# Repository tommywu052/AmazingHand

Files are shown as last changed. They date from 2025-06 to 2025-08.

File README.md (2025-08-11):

Project is licensed under [Apache 2.0](https://www.apache.org/licenses/LICENSE-2.0)

Mechanical design is licensed under a :
[Creative Commons Attribution 4.0 International License][cc-by].
[][cc-by]
[][cc-by]

[cc-by]: http://creativecommons.org/licenses/by/4.0/
[cc-by-image]: https://licensebuttons.net/l/by/4.0/88x31.png
[cc-by-shield]: https://img.shields.io/badge/License-CC%20BY-lightgrey.svg

# Amazing Hand project

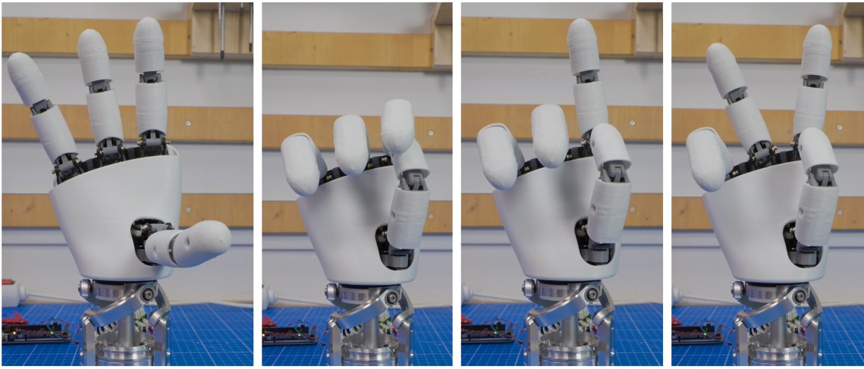
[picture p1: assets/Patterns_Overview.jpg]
Patterns


Robotic hands are often very expensive and not so expressive. More dexterous often needs cables and deported actuators in forearm i.e..

Aim of this project is to be able to explore humanoid hand possibilities on a real robot (and Reachy2 is the perfect candidate for that !) with moderate cost.
=> Wrist interface is designed for Reachy2's wrist (Orbita 3D), but it can be easily adapted to other robot's wrist...

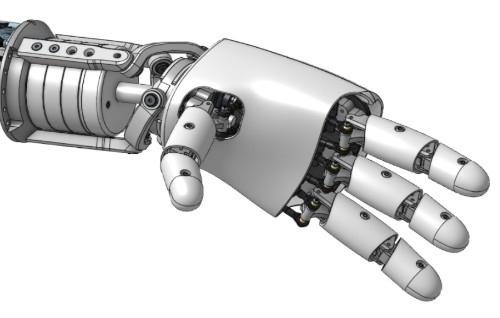
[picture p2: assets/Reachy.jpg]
Reachy


Amazing Hand is :
- 8 dofs humanoid hand with 4 fingers
- 2 phalanxes per finger articulated together
- flexible shells allmost everywhere
- All actuators inside the hand, without any cables
- 3D printable
- 400g weight
- low-cost (<200€)
- open-source

[AmazingHand_Overview](/docs/AmazingHand_Overview.pdf)

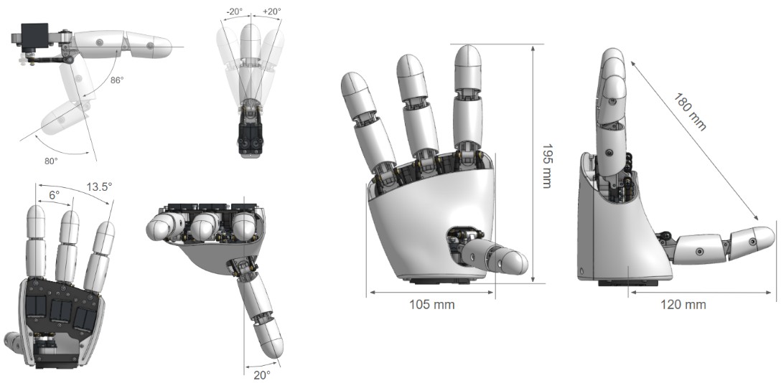
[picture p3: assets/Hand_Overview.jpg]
Hand Overview

Each finger is driven by parallel mechanism. 
That means 2x small Feetech SCS0009 servos are used to move each finger in flexion / extension & Abduction / Adduction

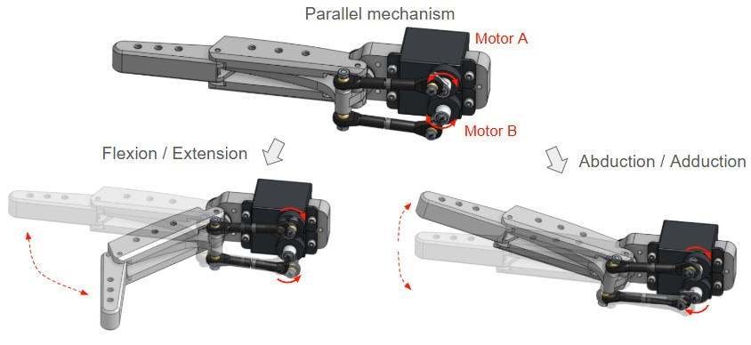
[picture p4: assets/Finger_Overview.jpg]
Finger Overview


2 ways of control are available :
- Use a Serial bus driver (waveshare i.e.) + Python script
- Use an Arduino + feetech TTL Linker

Detailed explaination are available for both ways and Basic demo software is available also.
Up to you !

## Table of contents

- [Python-based Hand Tracking System](#python-based-hand-tracking-system)
    - [Features](#features)
    - [Files](#files)
    - [Quick Start](#quick-start)
    - [Command Line Options](#command-line-options)
    - [Installation](#installation)
        - [CPU Version (Default)](#cpu-version-default)
        - [GPU Version (Enhanced Performance)](#gpu-version-enhanced-performance)
    - [Simulation Mode](#simulation-mode)
    - [Testing and Troubleshooting](#testing-and-troubleshooting)
    - [Control Modes](#control-modes)
    - [Configuration](#configuration)
    - [Hardware Requirements](#hardware-requirements)
    - [GPU Performance Optimization](#gpu-performance-optimization)
- [Build Resources](#build-resources)
    - [BOM (Bill Of Materials)](#bom-bill-of-materials)
    - [CAD Files and Onshape document](#CAD-files-and-onshape-document)
    - [Assembly Guide](#assembly-guide)
    - [Run_basic_Demo](#Run-basic-Demo)
- [Disclaimer](#disclaimer)
- [AmazingHand_tracking Demo](#AmazingHand_tracking_Demo) 
- [Project Updates & Community](#project-updates--community)
    - [Updates history](#updates-history)
    - [Project posts](#project-posts)
    - [To Do List](#to-do-list)
    - [FAQ](#faq)
    - [Contact](#contact)
    - [Thank you](#thank-you)

# Python-based Hand Tracking System

A new Python-based hand tracking system has been developed that provides real-time control of the Amazing Hand using MediaPipe hand tracking and inverse kinematics.

## Features

- **Real-time Hand Tracking**: Uses MediaPipe to detect hand landmarks from video stream
- **Inverse Kinematics**: Implements curl-based IK for natural finger movement control
- **Direct Motor Control**: Communicates directly with Feetech SCS0009 servos via serial connection
- **Natural Movement**: Robot fingers mimic physical hand movements including bending and positioning
- **Configurable Parameters**: Adjustable sensitivity, movement ranges, and motor positions

## Files

- **`amazing_hand_tracker_simple.py`**: Main Python script for hand tracking and robot control
- **`scsservo_sdk/`**: Custom SDK for Feetech SCS0009 servo communication
- **`r_hand.json`**: Robot hand configuration file with motor mappings
- **`requirement_simple.txt`**: Python dependencies for the tracking system (CPU version)
- **`requirements_gpu.txt`**: GPU-accelerated dependencies for enhanced performance

## Quick Start

1. Install dependencies:
   ```bash
   pip install -r requirement_simple.txt
   ```

2. Connect the Amazing Hand to your computer via USB (COM port on Windows)

3. Run the tracking system:
   ```bash
   python amazing_hand_tracker_simple.py --port COM3
   ```

4. Show your hand to the camera - the robot fingers will follow your movements

## Command Line Options

The script supports various command line arguments for different modes and configurations:

```bash
# Basic hand tracking with robot control
python amazing_hand_tracker_simple.py --port COM3

# Simulation mode (no physical robot connection)
python amazing_hand_tracker_simple.py --simulation

# Test individual motors
python amazing_hand_tracker_simple.py --test-motors --port COM3

# Enable debug output
python amazing_hand_tracker_simple.py --port COM3 --debug

# Use advanced IK instead of curl-based IK
python amazing_hand_tracker_simple.py --port COM3 --advanced-ik

# Specify different COM port
python amazing_hand_tracker_simple.py --port COM4

# Force GPU acceleration (if available)
python amazing_hand_tracker_simple.py --port COM3 --gpu

# Help and available options
python amazing_hand_tracker_simple.py --help
```

## Installation

### Prerequisites
- Python 3.7 or higher
- Webcam for hand tracking
- USB-to-Serial converter (for physical robot connection)

### Dependencies Installation

#### CPU Version (Default)
Install all required packages:
```bash
pip install -r requirement_simple.txt
```

Or install manually:
```bash
pip install opencv-python
pip install mediapipe
pip install numpy
pip install pyserial
```

#### GPU Version (Enhanced Performance)
For better performance with GPU acceleration, install GPU-enabled versions:

**⚠️ Important**: GPU acceleration support varies by Python version:

**Python 3.11 or earlier (Full GPU acceleration):**
```bash
# CUDA-enabled OpenCV (for NVIDIA GPUs)
pip install opencv-python-cuda

# GPU-accelerated MediaPipe
pip install mediapipe-gpu

# GPU-accelerated NumPy (optional, for large calculations)
pip install cupy-cuda11x  # Replace with your CUDA version

# Other dependencies remain the same
pip install pyserial
```

**Python 3.12 (Limited GPU acceleration - Current):**
```bash
# Standard packages (GPU acceleration limited)
pip install opencv-contrib-python
pip install mediapipe
pip install pyserial

# PyTorch with CUDA (this works on Python 3.12)
pip install torch torchvision torchaudio --index-url https://download.pytorch.org/whl/cu121
```

**Note**: GPU versions require:
- NVIDIA GPU with CUDA support
- CUDA Toolkit installed
- Compatible GPU drivers
- Windows: Visual Studio Build Tools
- Linux: GCC compiler

**Performance Benefits**:
- Faster hand tracking processing
- Reduced latency for real-time control
- Better performance with high-resolution cameras
- Smoother robot hand response

### Hardware Setup
1. Connect the Amazing Hand to your computer via USB
2. Ensure external 5V power supply is connected to the servos
3. Note the COM port (e.g., COM3 on Windows, /dev/ttyUSB0 on Linux)

## Simulation Mode

For testing without physical hardware, use simulation mode:
```bash
python amazing_hand_tracker_simple.py --simulation
```

In simulation mode:
- MediaPipe hand tracking works normally
- Motor commands are simulated (no physical movement)
- Useful for testing hand detection and IK calculations
- No COM port connection required

## Testing and Troubleshooting

### Test Motor Connections
```bash
python amazing_hand_tracker_simple.py --test-motors --port COM3
```

This will:
- Test communication with each servo
- Move each finger through its range of motion
- Verify motor IDs and connections
- Display servo feedback and status

### Debug Mode
```bash
python amazing_hand_tracker_simple.py --port COM3 --debug
```

Enables:
- Detailed console output
- Motor position logging
- IK calculation details
- MediaPipe landmark coordinates

## Control Modes

- **Curl-based IK**: Maps finger curl (bending) to servo positions for natural movement
- **Advanced IK**: Alternative inverse kinematics approach (experimental)
- **Test Mode**: Test individual motors and verify connections

## Configuration

The system can be configured through parameters in the Python script:
- `CURL_GAIN_PER`: Sensitivity of finger bending
- `OPEN_POS_PER`/`CLOSE_POS_PER`: Position limits for each finger
- `CENTER_OFFSET`: Compensation for finger alignment
- `MOVEMENT_SMOOTHING`: Smoothing factor for movement response

## Hardware Requirements

- Amazing Hand with Feetech SCS0009 servos
- USB-to-Serial converter (or direct USB connection)
- Webcam for hand tracking
- External 5V power supply for servos

## GPU Performance Optimization

### When to Use GPU Version
- **High-resolution cameras** (1080p or higher)
- **Multiple hand tracking** scenarios
- **Low-latency requirements** for real-time control
- **Processing-intensive applications** with complex IK calculations

### Performance Comparison
| Feature | CPU Version | GPU Version | Improvement |
|---|---|---|---|
| Hand tracking speed | ~30 FPS | ~60+ FPS | 2x faster |
| Latency | ~33ms | ~16ms | 2x lower |
| Camera resolution | Up to 720p | Up to 4K | 4x higher |
| Multi-hand support | Limited | Excellent | Significant |

### GPU Requirements
- **NVIDIA GPU**: GTX 1060 or better (6GB+ VRAM recommended)
- **CUDA Support**: CUDA 11.0 or higher
- **Driver Version**: Latest NVIDIA drivers
- **Memory**: 8GB+ system RAM, 6GB+ VRAM

### ⚠️ Python Version Compatibility
**Important**: GPU acceleration has different levels of support depending on your Python version:

- **Python 3.11 or earlier**: Full GPU acceleration available
  - `opencv-contrib-python-cuda` packages available
  - `mediapipe-gpu` packages available
  - Maximum performance improvement

- **Python 3.12 (Current)**: Limited GPU acceleration
  - PyTorch CUDA support works (detected in your system)
  - MediaPipe falls back to CPU (expected behavior)
  - OpenCV CUDA packages not yet available
  - Still provides some GPU benefits through PyTorch

**Recommendation**: For maximum GPU performance, consider using Python 3.11 until Python 3.12 packages become available.

This system provides a simplified alternative to the original Rust/Dora/Mujoco implementation while maintaining the core functionality of real-time hand tracking and robot control.

# Build Resources
## BOM (Bill Of Materials)
List of all needed components is available here:  
[AmazingHand BOM](https://docs.google.com/spreadsheets/d/1QH2ePseqXjAhkWdS9oBYAcHPrxaxkSRCgM_kOK0m52E/edit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)  
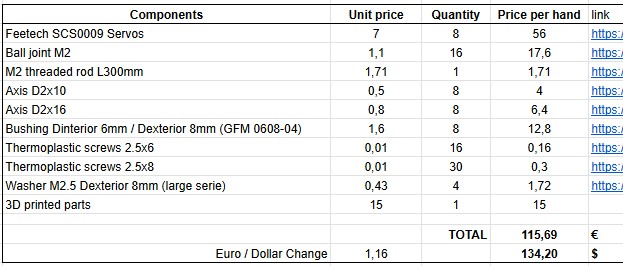
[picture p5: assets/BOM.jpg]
BOM


And remember to add control choice cost (2 options detailed previously)

Detailed for custom 3D printed parts are here : 
[3Dprinted parts](https://docs.google.com/spreadsheets/d/1QH2ePseqXjAhkWdS9oBYAcHPrxaxkSRCgM_kOK0m52E/edit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)

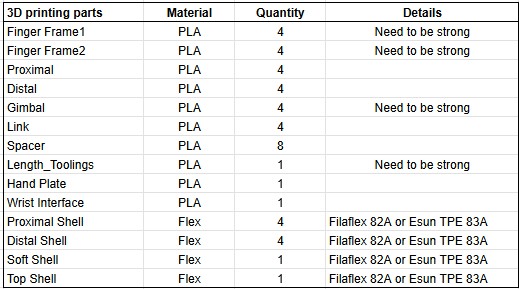
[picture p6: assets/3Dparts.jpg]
3Dparts


Here is guide to explain how to print all the needed custom parts :
[=> 3D Printing Guide](/docs/AmazingHand_3DprintingTips.pdf)
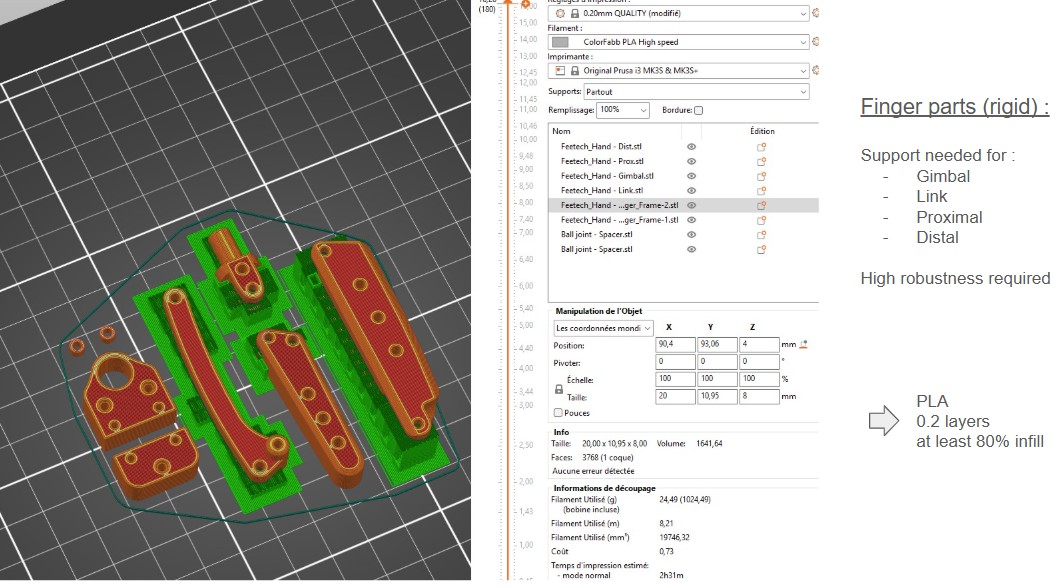
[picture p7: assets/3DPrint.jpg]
3DPrint_example
 

## CAD Files and Onshape document
STL and Steps files can be found [here](https://github.com/pollen-robotics/AmazingHand/tree/main/cad) 

Note that Fingers are the same if you want to build a left hand, but some parts are symetrical. Specific right hand parts are preceded by an "R", and other of the left hand parts by an "L".

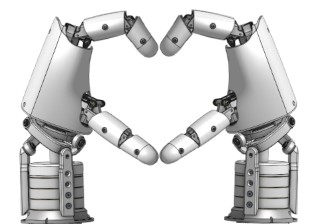
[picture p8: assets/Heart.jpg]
Heart


Everyone can access the Onshape document too:   
[Link Onshape](https://cad.onshape.com/documents/430ff184cf3dd9557aaff2be/w/e3658b7152c139971d22c688/e/bd399bf1860732c6c6a2ee45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)  

Note that predefined position are available in "named position" tooling, with corresponding servos angles

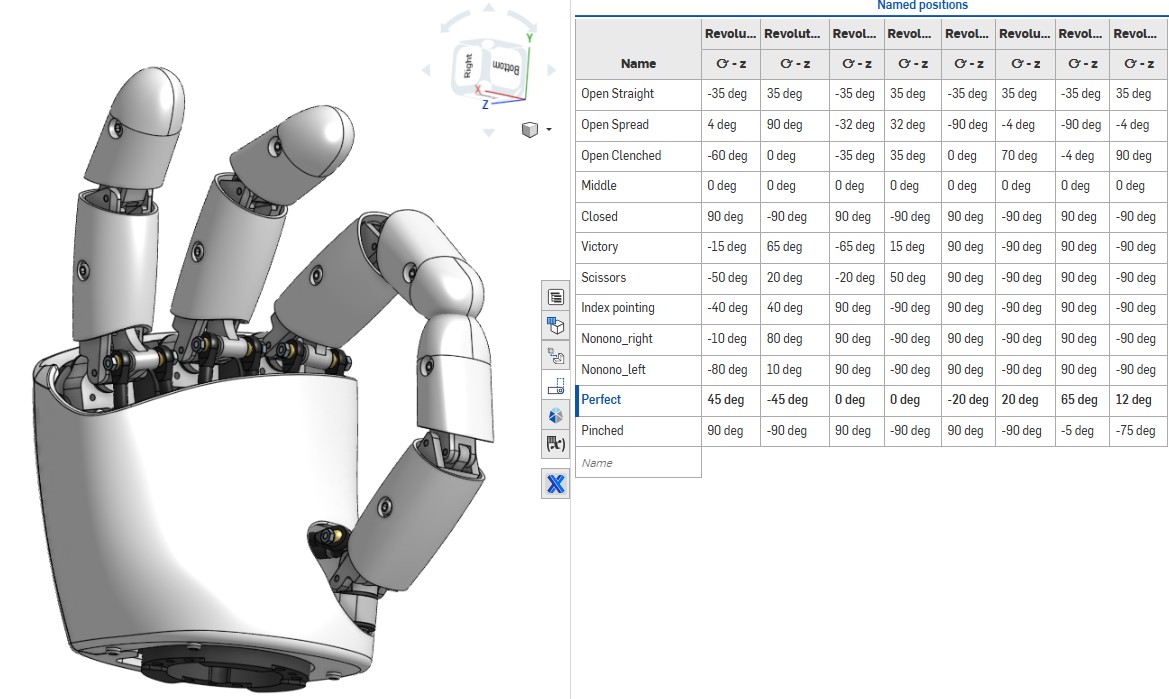
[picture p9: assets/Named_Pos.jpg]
Onshape&Named_Pos
  

## Assembly Guide

Assembly guide for the Amazing Hand in combination with standards components in the BOM is here :  
[=> Assembly Guide](/docs/AmazingHand_Assembly.pdf)  
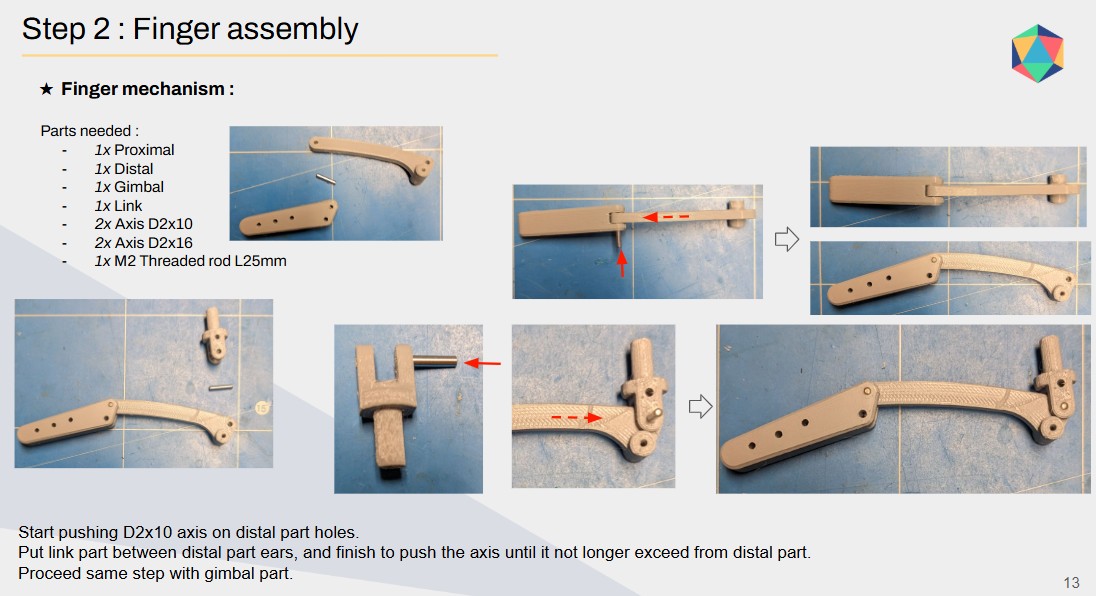
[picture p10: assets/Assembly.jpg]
Assembly_example
  

You will need simple program / script to calibrate each fingers, available here :
- With Python & Waveshare serial bus driver : [here](https://github.com/pollen-robotics/AmazingHand/tree/main/PythonExample)
- With Arduino & TTLinker : [here](https://github.com/pollen-robotics/AmazingHand/tree/main/ArduinoExample)

Note that this assembly guide is for a standalone Right hand.

If you need to build a standalone Left hand, you can keep the sames IDs for servos location, and select if it's a right or left hand in the software.

BUT, if you need to build both right and left hands to plug them on a robot, you will have to attribute differents IDs for right and left hands. You can't have same ID for different servos on the same serial bus...

## Run basic Demo

Basic Demo which is available with both Python & Arduino.

You will need external power supply to be able to power the 8 actuators inside the hand.

If you don't have one already, simple external power supply could be a DC/DC 220V -> 5V / 2A adapter with jack connector.
Check on the Bom List :
[AmazingHand BOM](https://docs.google.com/spreadsheets/d/1QH2ePseqXjAhkWdS9oBYAcHPrxaxkSRCgM_kOK0m52E/edit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) 

- Python script : "AmazingHand_Demo.py" [here](https://github.com/pollen-robotics/AmazingHand/tree/main/ArduinoExample)
  
- Arduino program : "AmazingHand_Demo.ino" [here](https://github.com/pollen-robotics/AmazingHand/tree/main/PythonExample)

https://github.com/user-attachments/assets/485fc1f4-cc57-4e59-90b5-e84518b9fed0

# Disclaimer

I noticed some variations between theorical angles for Flexion / Extension, Abduction / Adduction and angles in real life prototypes. This is probably due to several sources of variation (3D printed parts are not perfect, balljoint rods are manually adjusted one by one, esrvo horn rework, flexibility of plastic parts...).

This design has not yet bene tested for long and complex prehensive tasks. Before to be able to grasp objetcs safely (that means without damaging servos or mehanical parts), kind of smart software need to be build.
SCS0009 servos have smart capaibilities as:
- Torque enable / disable
- Torque feedback
- Current position sensor
- Heat temperature feedback
- ...

# AmazingHand advanced Demo
Tracking demo (https://www.youtube.com/watch?v=U0TfeG3ZUto)

For more advanced usage using inverse/forward kinematics there are several examples in the [Demo](Demo) directory along with some useful tools to test/configure the motors.

# Project Updates & Community
## Updates from community

Amazing Base for the amazing hand : 
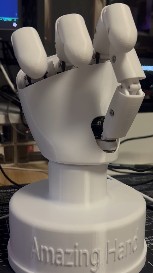
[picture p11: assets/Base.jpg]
Base

STL or Step file can be found [here](https://github.com/pollen-robotics/AmazingHand/tree/main/cad) 

Specific Chinese BOM available here :
[Chinese BOM](https://docs.google.com/spreadsheets/d/1fHZiTky79vyZwICj5UGP2c_RiuLLm89K8HrB3vpb2h4/edit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)

Thanks to Jianliang Shen !

## To Do List
- Design small custom pcb with serial hub and power supply functions, to fit everything in the hand
- Test with prehensive tasks 
      => Add smarter behaviour for closing hand, based on available motors feedbacks
- Study possibility to have 4 different fingers length, or add a 5th finger
- Study possibility to use STS3032 feetedch motors instead of SCS0009
      => Stronger for quite the same volume, but servo horn is different
- Study possibility to add compliancy by replacing rigid links to springs
- Add fingertip sensor to push one step higher smart control

## FAQ
WIP

## Contact

You can reach public discord channel here : 
[Discord AmazingHand](https://discord.com/channels/519098054377340948/1395021147346698300)

Or 
[Contact me or Pollen Robotics](/docs/contact.md)

## Thank you
Huge thanks to those who have contributed to this project so far:
- [Steve N'Guyen](https://github.com/SteveNguyen) for beta testing, Feetech motors integration in Rustypot, Mujoco/Mink and hand tracking demo
- [Pierre Rouanet](https://github.com/pierre-rouanet) for Feetech motors integration in pypot  
- [Augustin Crampette](https://fr.linkedin.com/in/augustin-crampette) & [Matthieu Lapeyre](https://www.linkedin.com/in/matthieulapeyre/) for open discussions and mechanical advices

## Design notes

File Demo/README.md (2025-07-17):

# Example control for the Pollen Robotics "AmazingHand" (a.k.a. AH!)

## How to use:
- Install Rust: https://www.rust-lang.org/tools/install
- Install uv: https://docs.astral.sh/uv/getting-started/installation/
- Install dora-rs: https://dora-rs.ai/docs/guides/Installation/installing
  - start the daemon: `dora up`

- Clone this repository and in a console from the directory run:
- `uv venv --python 3.12`
- To run the webcam hand tracking demo in simulation only:
  - `dora build dataflow_tracking_simu.yml --uv` (needs to be done only once)
  - `dora run dataflow_tracking_simu.yml --uv`
- To run the webcam hand tracking demo with real hardware:
  - `dora build dataflow_tracking_real.yml --uv` (needs to be done only once)
  - `dora run dataflow_tracking_real.yml --uv`
- To run a simple example to control the finger angles in simulation:
  - `dora build dataflow_angle_simu.yml --uv` (needs to be done only once)
  - `dora run dataflow_angle_simu.yml --uv`

## Hand Setup

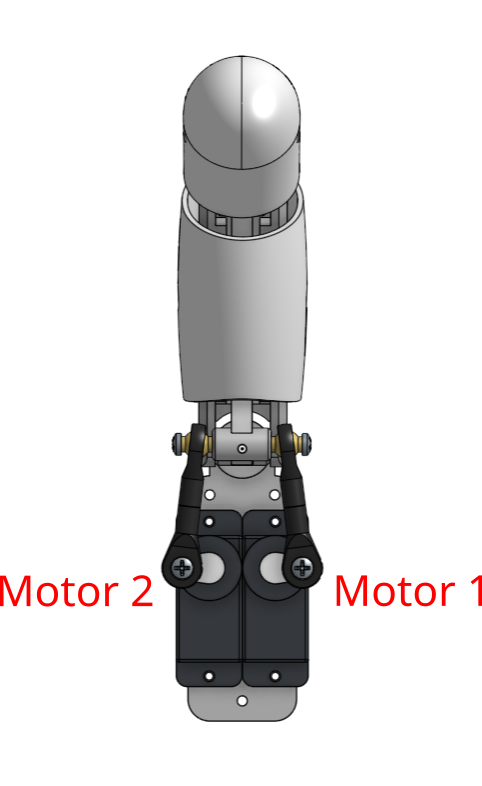
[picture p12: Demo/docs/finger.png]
Motors naming Motors naming for each finger


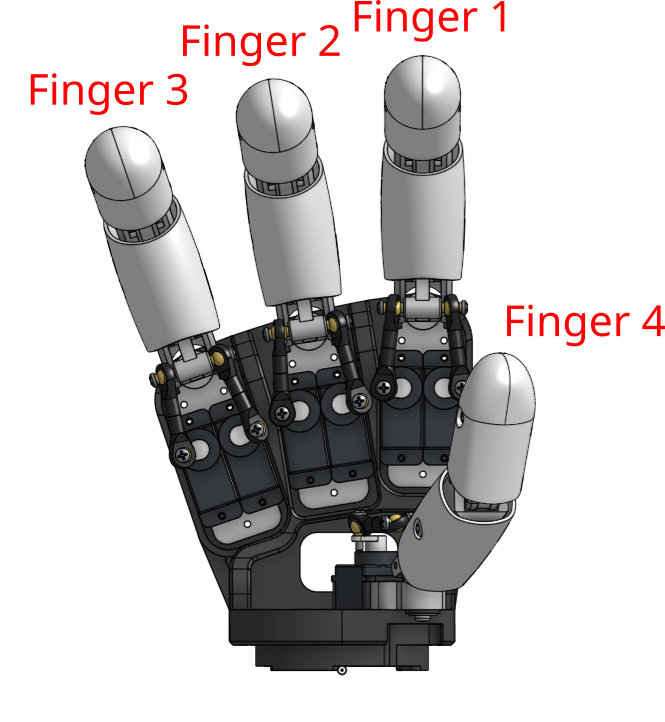
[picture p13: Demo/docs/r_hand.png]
Fingers naming Fingers naming for each hand


Be sure to adapt the configuration file [r_hand.toml](AHControl/config/r_hand.toml) for your particular hand.
You can use the software tools located in [AHControl](AHControl).

## Details

- [AHControl](AHControl) contains a dora-rs node to control the motors, along with some useful tools to configure them.
- [AHSimulation](AHSimulation) contains a dora-rs node to simulate the hand and get the inverse kinematics.
- [HandTracking](HandTracking) contains a dora-rs node to track hands from a webcam and use it as target to control AH!.

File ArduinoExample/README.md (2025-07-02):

Feetech SCS0009 with Arduino tutorial :

[https://www.robot-maker.com/forum/topic/14804-presentation-et-fonctionnement-des-servomoteurs-feetech/]

Make sure to first install Arduino librairie "SCServo".

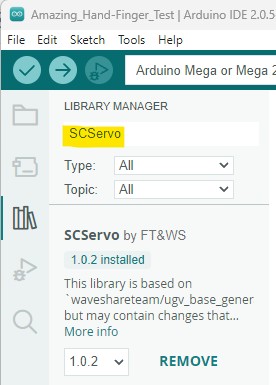
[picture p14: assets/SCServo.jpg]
Install_SCServo_librairy Install SCServo with Arduino librairie manager


Use Feetech software to set IDs :
[https://github.com/Robot-Maker-SAS/FeetechServo/tree/main/feetech%20debug%20tool%20master/FD1.9.8.2)

# Summary in English (tutorial link is in french...)

## Wiring for link mode to change IDs of servos :

Upload Blink example program on arduino before opening serial port com with Feeetech software.

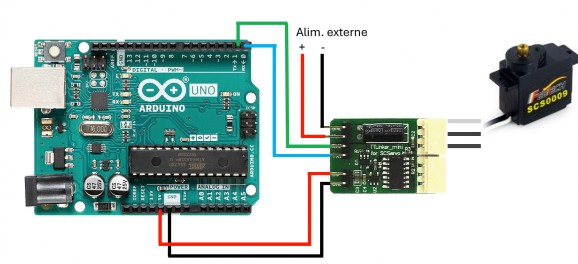
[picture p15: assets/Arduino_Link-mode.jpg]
Link_Mode


Rx arduino pin connected to Tx pin on TTLinker / Tx arduino pin connected to Rx pin on TTLinker

## Wiring for control mode with arduino :

Upload custom program on arduino board.

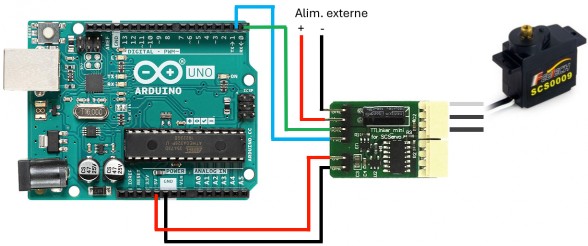
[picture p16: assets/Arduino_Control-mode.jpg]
Control_Mode


Rx arduino pin connected to Tx pin on TTLinker / Tx arduino pin connected to Rx pin on TTLinker

- For an arduino Uno (or other small arduinos with only one serial port), Serial communication setup need to be as follow :
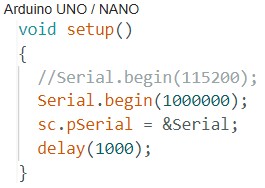
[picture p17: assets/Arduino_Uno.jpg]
Arduino_Uno_PortCom


- Note that Arduino used in this case is a Mega which have several serial ports embedded, so Serial communication setup need to be as follow :
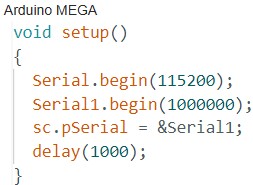
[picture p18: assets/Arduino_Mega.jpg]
Arduino_Mega_PortCom


Rx and Tx pin used on arduino Mega are RX1 & TX1 (19 & 18)

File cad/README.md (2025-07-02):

Before print custom mechanical parts, please refer to 3D printing guide here :
[=> 3D Printing Guide](../docs/AmazingHand_3DprintingTips.pdf)
3DPrint_example

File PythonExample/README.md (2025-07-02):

Tutorial for settings IDs with Feetech Software, and Serial bus driver : [https://www.robot-maker.com/forum/tutorials/article/168-brancher-et-controler-le-servomoteur-feetech-sts3032-360/]

Use Feetech software to set IDs : [https://github.com/Robot-Maker-SAS/FeetechServo/tree/main/feetech%20debug%20tool%20master/FD1.9.8.2)]

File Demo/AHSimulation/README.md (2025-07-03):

# Mujoco simulation of the hand

Contains the Mujoco model and assets along with a Python node which sets the inverse kinematics problem.

[Mink](https://github.com/kevinzakka/mink) is used to solve the IK as a QP problem.

We can chose to either control the fingertips position (useful for the hand tracking demo) or the distal phalanges orientation.

The AmazingHand model was exported from CAD using [onshape-to-robot](https://github.com/Rhoban/onshape-to-robot)

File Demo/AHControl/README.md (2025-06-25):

# Motor control node

The motor configuration is set in a TOML file (cf. [r_hand.toml](config/r_hand.toml)).
In this file you can set the motors ID, and angle offsets for each finger.

# Tools
- *change_id*: to help you change the id of a motor. `cargo run --bin=change_id -- -h` for a list of parameters
- *goto*: to move a single motor to a given position. `cargo run --bin=goto -- -h` for a list of parameters
- *get_zeros*: to help you set the motor zeros, it sets the motors in the compliant mode and write the TOML file to the console. `cargo run --bin=get_zeros -- -h` for a list of parameters
- *set_zeros*: to move the hand in the "zero" position according to the config file. `cargo run --bin=set_zeros -- -h` for a list of parameters

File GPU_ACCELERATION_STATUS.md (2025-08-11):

# GPU Acceleration Status for Amazing Hand Tracker

## Current Status: ✅ Working with Limitations

Your GPU acceleration setup is **working correctly** for Python 3.12 on Windows, but with expected limitations.

## What's Working ✅

1. **PyTorch CUDA Detection**: 
   - RTX 4090 detected successfully
   - CUDA 12.8 support confirmed
   - GPU memory and compute available

2. **GPU Mode Features**:
   - `--gpu` flag working
   - `--gpu-test` flag working
   - Performance monitoring active
   - Higher resolution support (720p vs 480p)
   - Enhanced MediaPipe configuration

3. **Fallback Behavior**:
   - Automatic CPU fallback for MediaPipe (expected)
   - Graceful degradation when GPU packages unavailable
   - Still provides some GPU benefits through PyTorch

## What's Limited ⚠️

1. **MediaPipe GPU Acceleration**:
   - Falls back to CPU mode (expected for Python 3.12)
   - Limited by package availability, not your hardware

2. **OpenCV CUDA Acceleration**:
   - CUDA packages not available for Python 3.12 on Windows
   - Using standard OpenCV with CPU processing

## Why This Happens

**Python 3.12 Compatibility Issue**:
- Python 3.12 released October 2023 (very recent)
- Most CUDA-enabled packages don't have pre-built wheels yet
- Windows packages lag behind Linux packages
- This is a temporary limitation, not a permanent issue

## Performance Impact

**Current Setup (Python 3.12)**:
- **Hand Tracking**: CPU-based, ~15-25 FPS
- **Resolution**: 720p (GPU mode) vs 480p (CPU mode)
- **Latency**: Moderate (CPU processing)
- **GPU Benefits**: Limited to PyTorch operations

**Full GPU Setup (Python 3.11)**:
- **Hand Tracking**: GPU-accelerated, ~30-60 FPS
- **Resolution**: Up to 4K
- **Latency**: Low (GPU processing)
- **GPU Benefits**: Full acceleration

## Solutions

### Option 1: Wait for Python 3.12 Support (Recommended)
- Packages will become available over time
- No action needed
- Current setup is optimal for Python 3.12

### Option 2: Downgrade to Python 3.11
- Full GPU acceleration available
- Requires reinstalling Python and packages
- Maximum performance

### Option 3: Use Current Setup
- Already working optimally for Python 3.12
- Provides some GPU benefits
- Stable and reliable

## Current Performance

Your current setup is **already optimal** for Python 3.12:
- ✅ GPU detection working
- ✅ Performance monitoring active
- ✅ Higher resolution support
- ✅ Graceful fallback behavior
- ✅ Stable operation

## Conclusion

**Don't worry about the "CPU mode" message** - this is expected and correct behavior for Python 3.12 on Windows. Your GPU acceleration is working as intended given the current package limitations.

The system will automatically use GPU acceleration when available and fall back to CPU when needed, ensuring optimal performance for your current setup.

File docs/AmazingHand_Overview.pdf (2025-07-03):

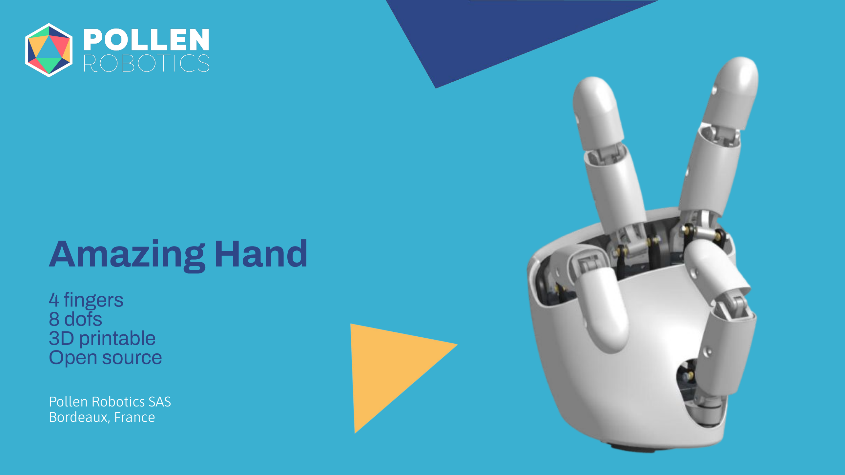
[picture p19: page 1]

Pollen Robotics SAS
Bordeaux, France

# Amazing Hand

### 4 fingers 8 dofs 3D printable Open source

## Amazing Hand

## Finger mechanism

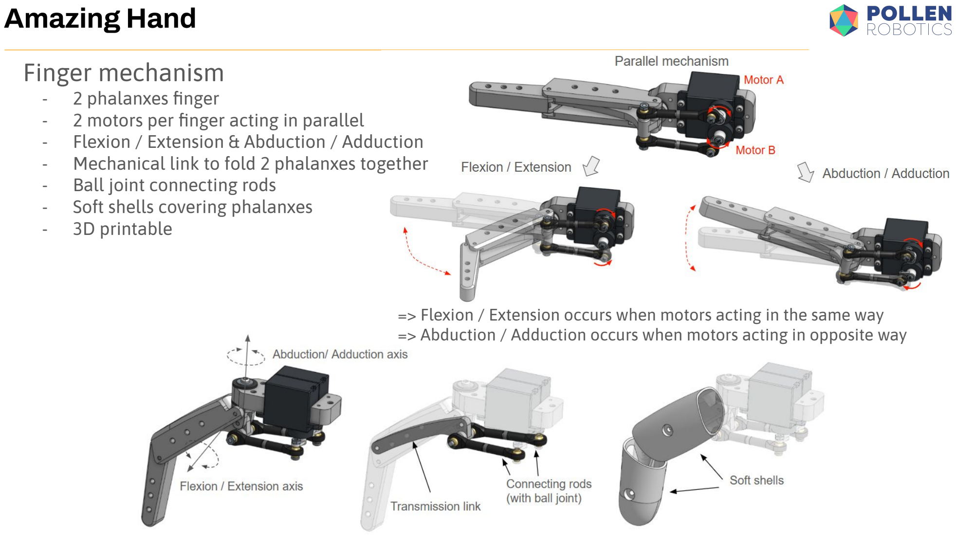
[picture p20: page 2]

- 2 phalanxes finger
- 2 motors per finger acting in parallel
- Flexion / Extension & Abduction / Adduction
- Mechanical link to fold 2 phalanxes together
- Ball joint connecting rods
- Soft shells covering phalanxes
- 3D printable

=> Flexion / Extension occurs when motors acting in the same way => Abduction / Adduction occurs when motors acting in opposite way

## Amazing Hand

## Hand design

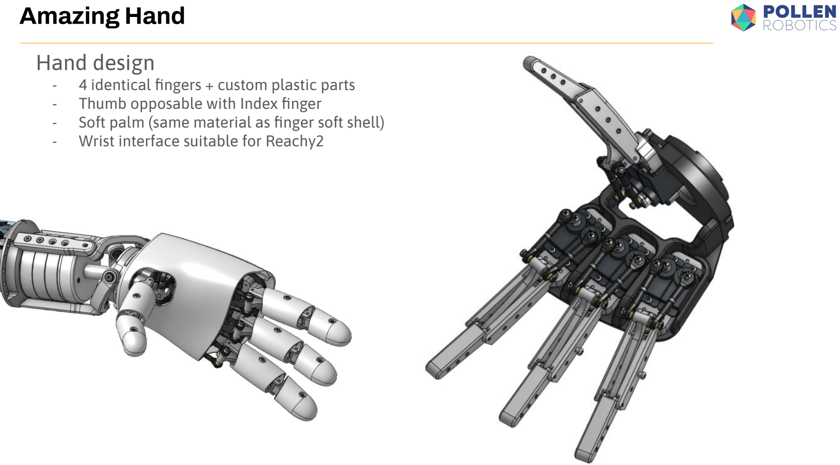
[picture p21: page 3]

- 4 identical fingers + custom plastic parts
- Thumb opposable with Index finger
- Soft palm (same material as finger soft shell)
- Wrist interface suitable for Reachy2

## Amazing Hand

## Technical details

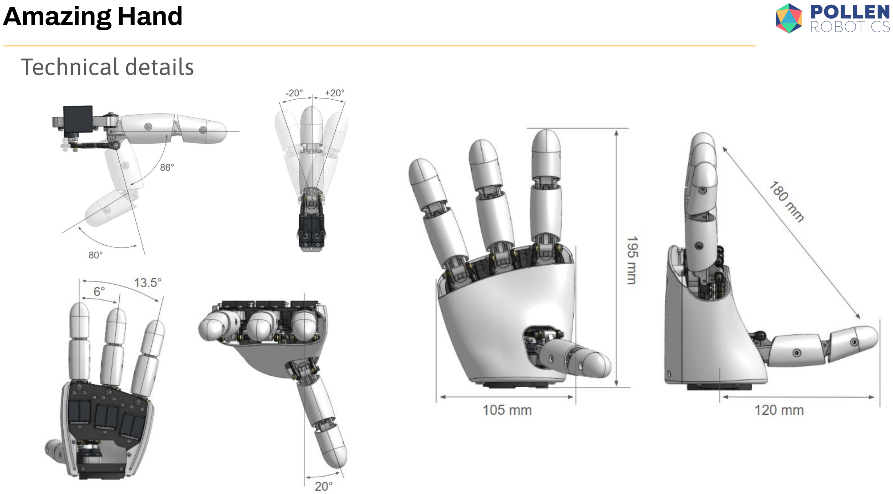
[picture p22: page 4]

## Amazing Hand

## Some of possible patterns

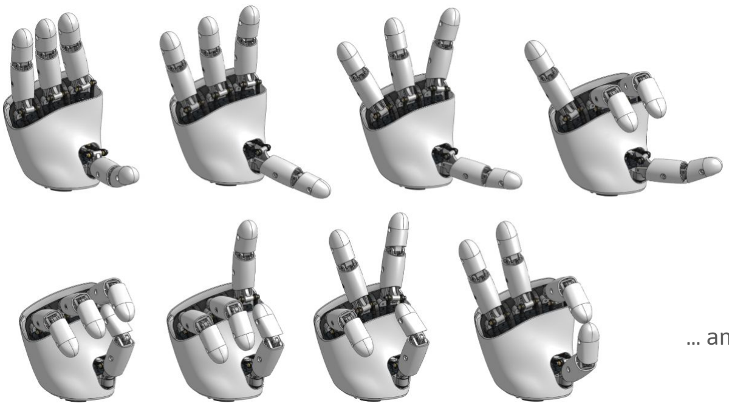
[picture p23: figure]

## … and others

## Amazing Hand

## Specifications

- x8 smart actuators (feetech SCS0009)
- DC Supply 5V / Max current 3A
- Weight : 400g
- Up to 1Kg payload
- 3D Printed suitable
- Fully open source (will be soon on github)
- Bom cost <200€ (assembly 5 - 6 hours)

It will be easy to :
- Add 5th finger (but will increase overall width)
- Size differently each finger
- Change position of fingers
- Add fingertip sensor (depends of which sensor obviously)
- Change wrist interface

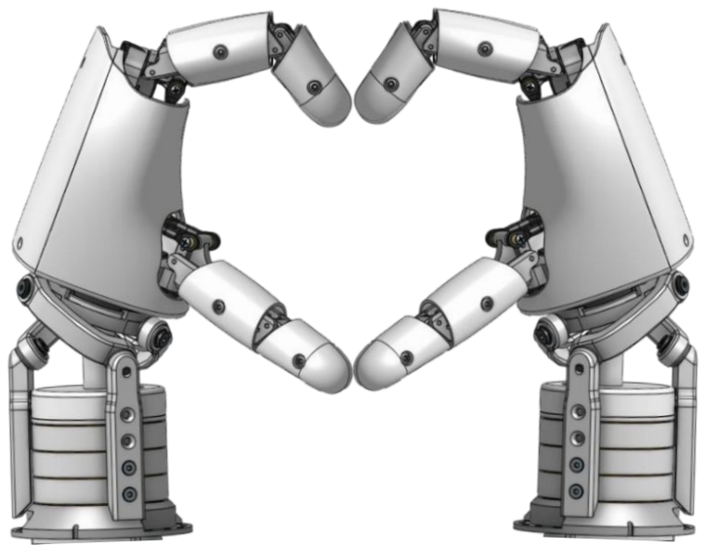
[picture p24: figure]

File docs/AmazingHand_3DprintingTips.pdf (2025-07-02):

## Finger parts (rigid) :

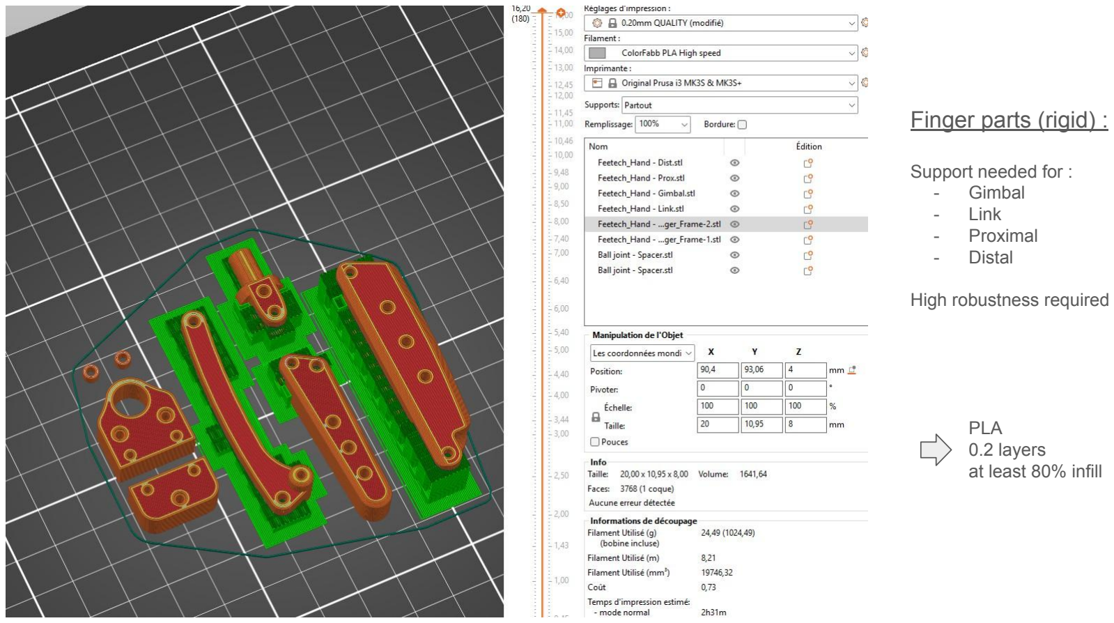
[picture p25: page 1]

Support needed for :
- Gimbal
- Link
- Proximal
- Distal

High robustness required

PLA
0.2 layers
at least 80% infill

## Finger parts (flex) :

No support needed

Flexibility required

Filaflex 82A
0.2 layers
between 40 & 70% infill

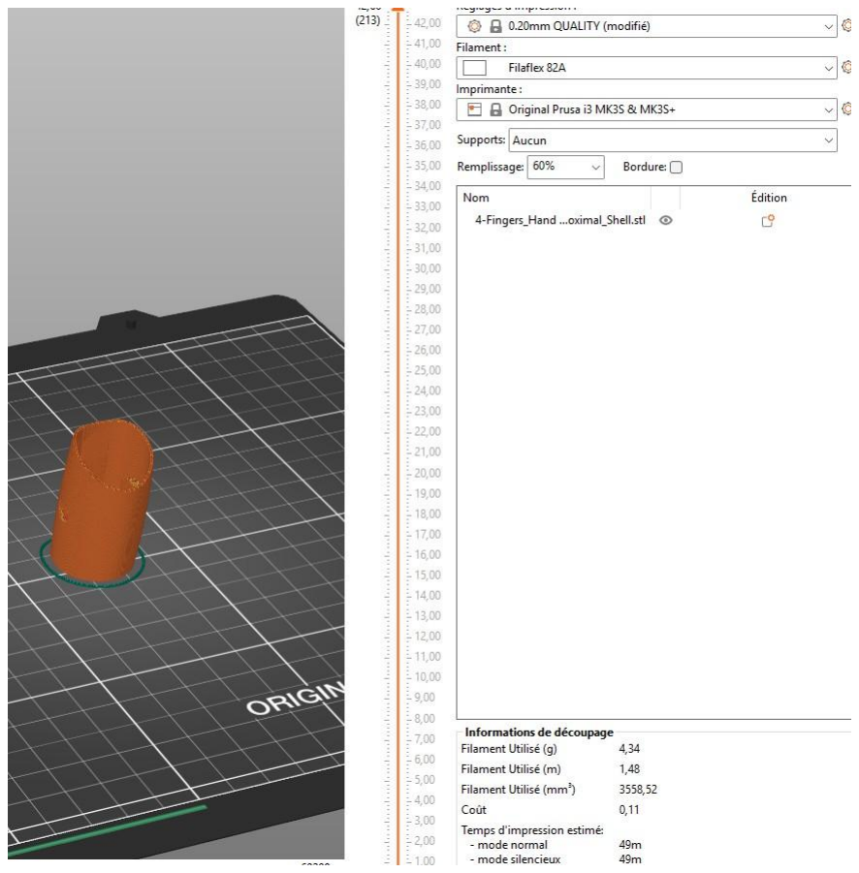
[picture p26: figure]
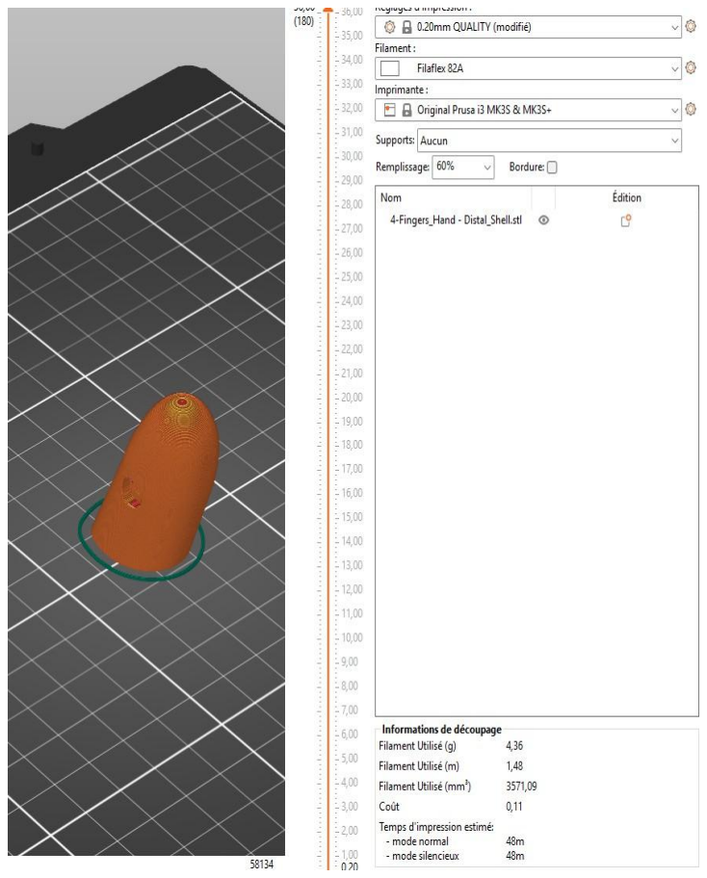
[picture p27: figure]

/!\ Flexible material as Filaflex or TPU is quite hard to print and need a very short distance between extruder and hot end.
Print parameters are specific for each filament and 3D printing machine, so several tests should be needed to obtain perfect result. Be strong ! In general :
- Don’t fill to much the part, it will increase his stiffness
- Don’t use support, it’s often a mess to retire it
- Print parts one by one, to avoid unwanted bridges
- Deactivate “fill gaps” parameters, it could create over thickness randomly
- Try to minimize retractation needed for printing, it could create thin wires that are difficult to remove
Sometimes it’s not possible to respect all these tips, you will have to be patient and precocious to clean flexible parts… Flexible has strong adhesion to printer bed, remember to remove the part quickly after it is finished to prevent bed damages.

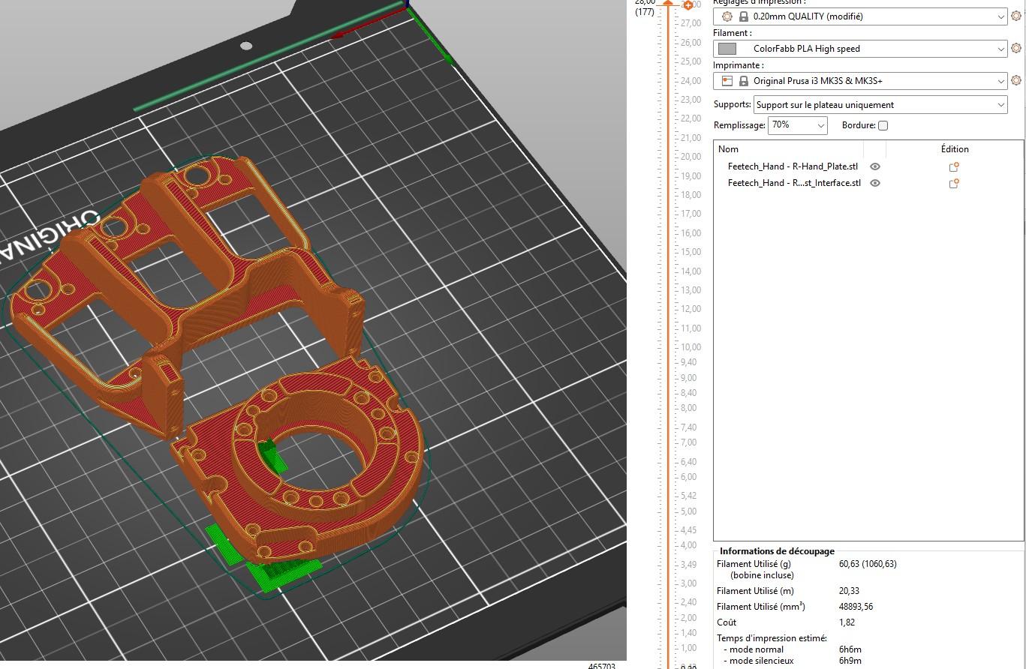
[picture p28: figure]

## Hand parts (rigid) :

Support needed for
- Wrist interface

Robustness required

PLA
0.2 layers
between 60 & 80% infill

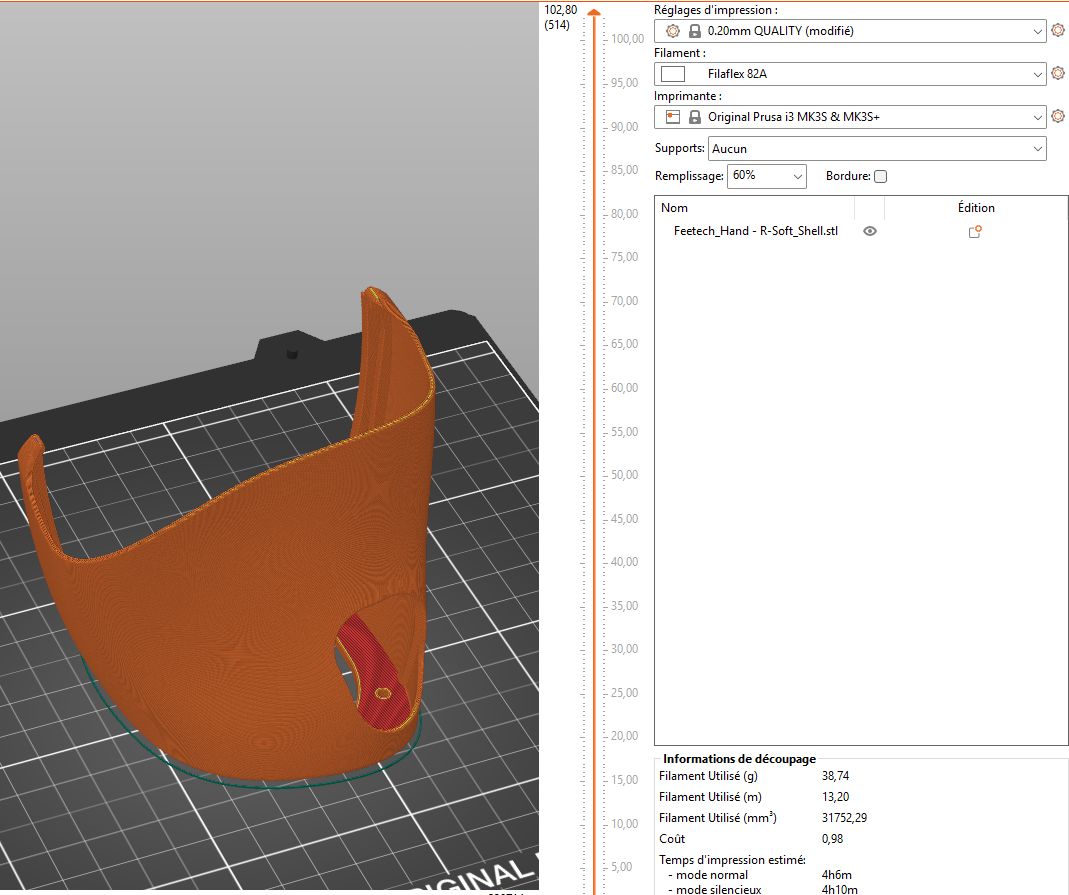
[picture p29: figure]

## Hand shell (flex) :

No support needed

Flexibility required

Filaflex 82A
0.2 layers
between 40 & 70% infill

/!\ Flexible material as Filaflex or TPU is quite hard to print and need a very short distance between extruder and hot end.

Print parameters are specific for each filament and 3D printing machine, so several tests should be needed to obtain perfect result. Be strong !

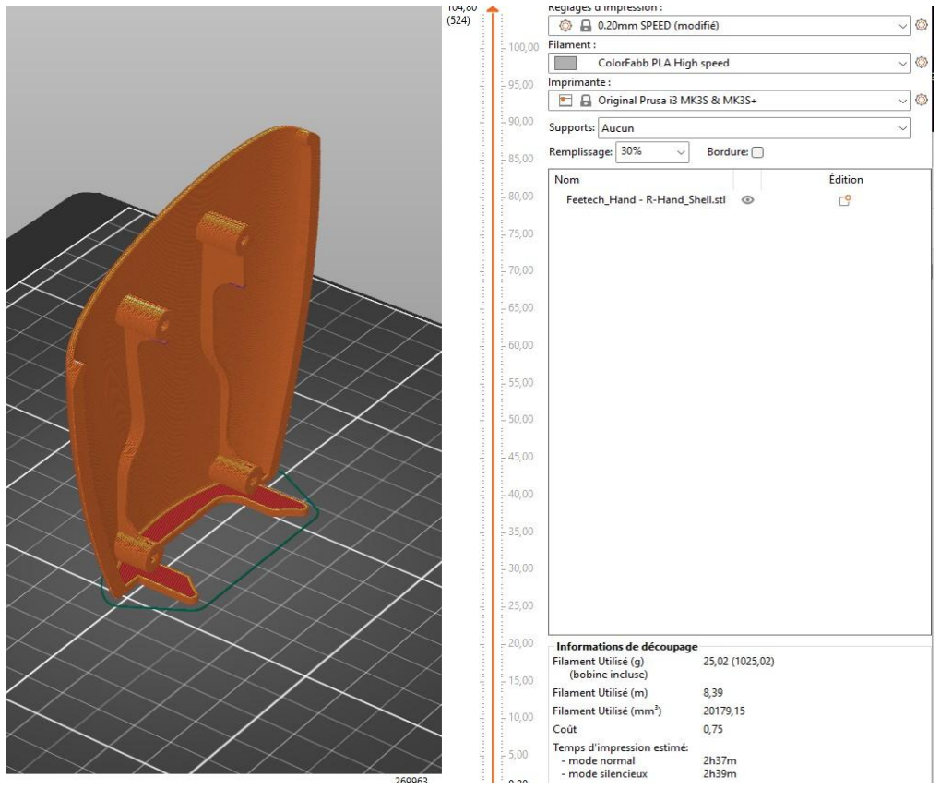
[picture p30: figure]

## Hand shell (rigid) :

No support needed
No robustness required

PLA
0.2 layers
between 20 & 40% infill

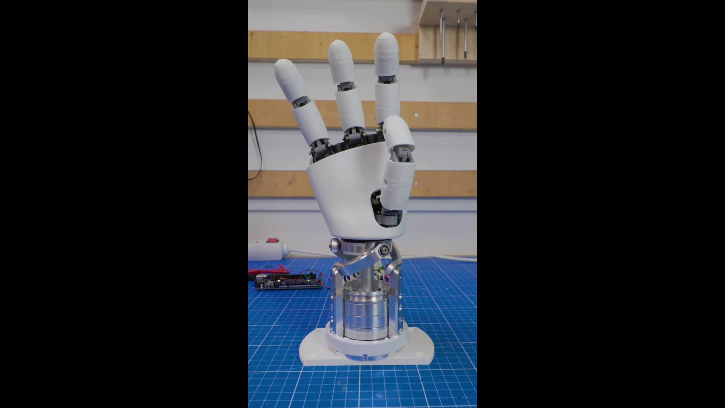
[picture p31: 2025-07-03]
assets/basic_demo_shot.png

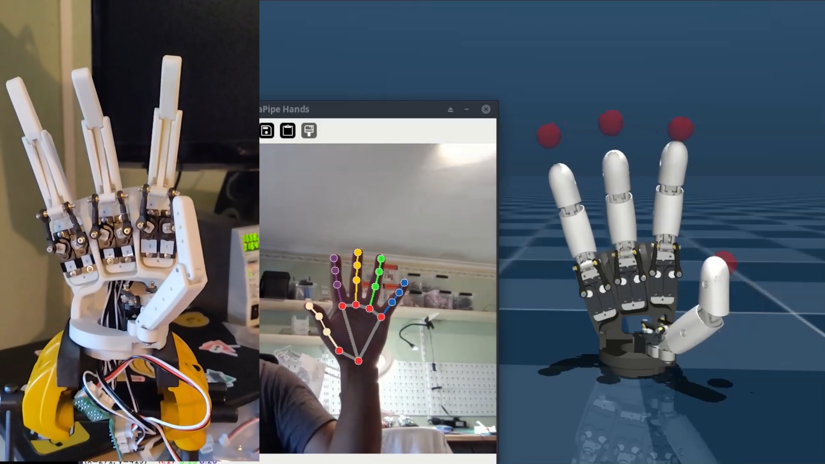
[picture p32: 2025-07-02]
assets/hand_tracking.png

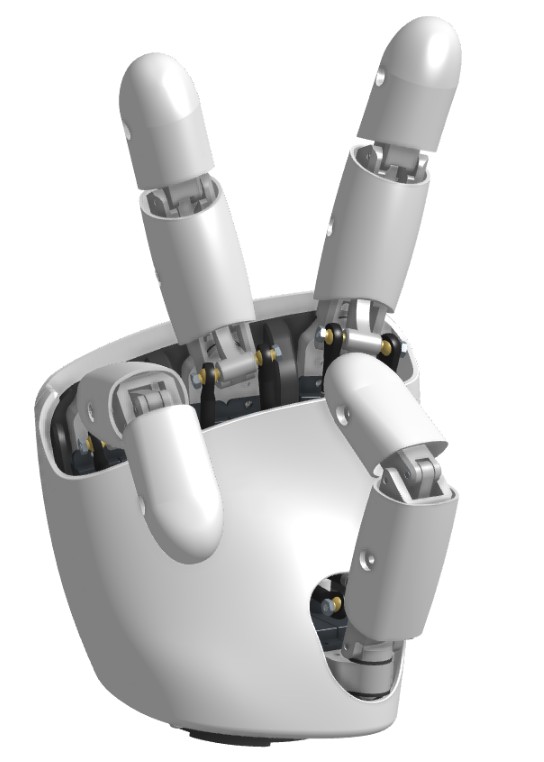
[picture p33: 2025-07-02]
assets/AmazingHand_Couv.jpg

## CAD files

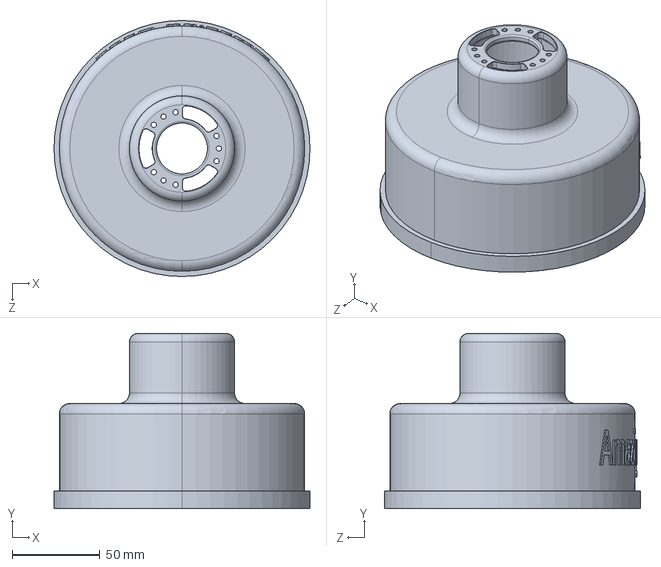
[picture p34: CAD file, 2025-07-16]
cad/step/Amazing Hand base.STEP
146.0 x 100.0 x 146.0 mm

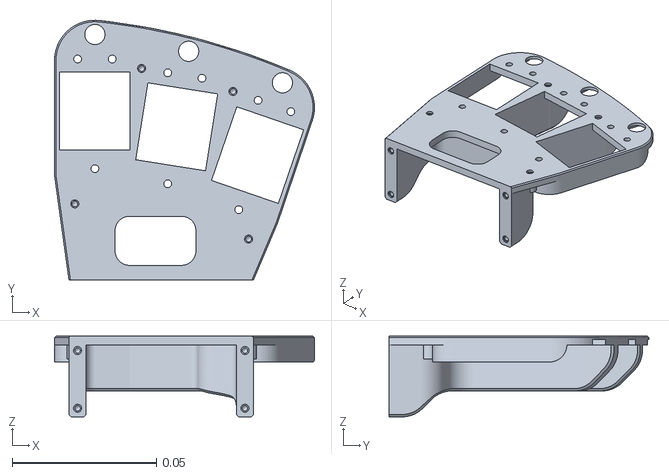
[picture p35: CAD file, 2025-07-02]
Demo/AHSimulation/AHSimulation/AH_Right/mjcf/assets/r_hand_plate.stl
0.0901 x 0.0899 x 0.028

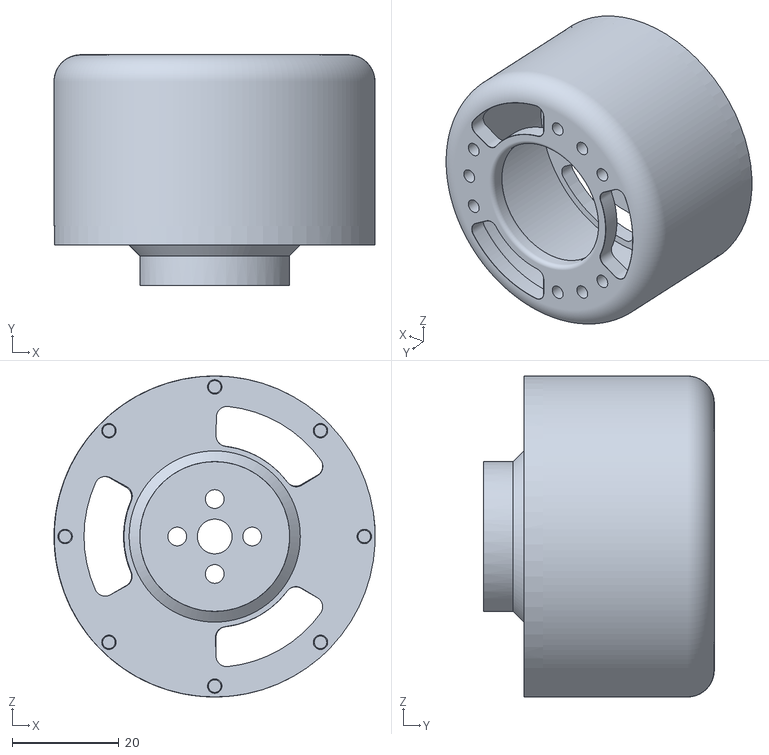
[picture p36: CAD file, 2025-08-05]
Hand base connet_connector_so100.STL
60.0 x 43.1 x 60.0

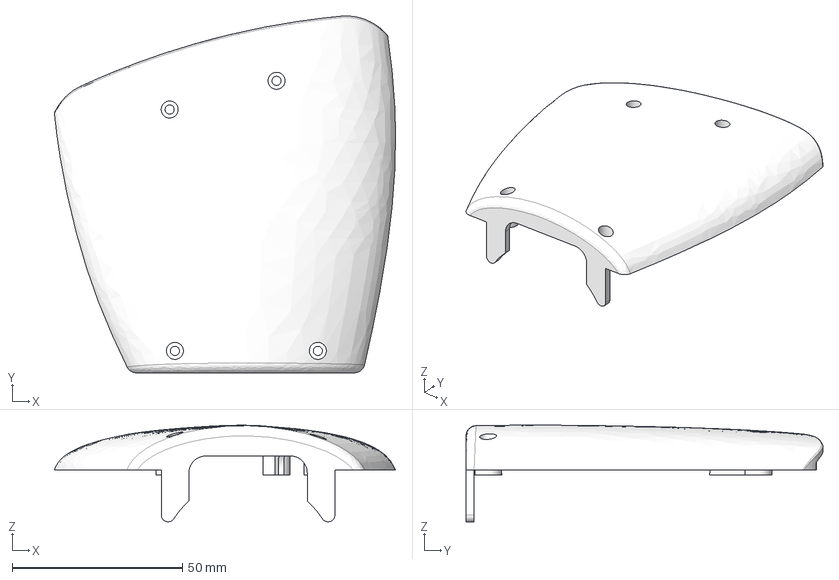
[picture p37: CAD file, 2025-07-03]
cad/step/Amazing Hand Parts - L-Top_Shell.step
100.2 x 104.9 x 28.4 mm

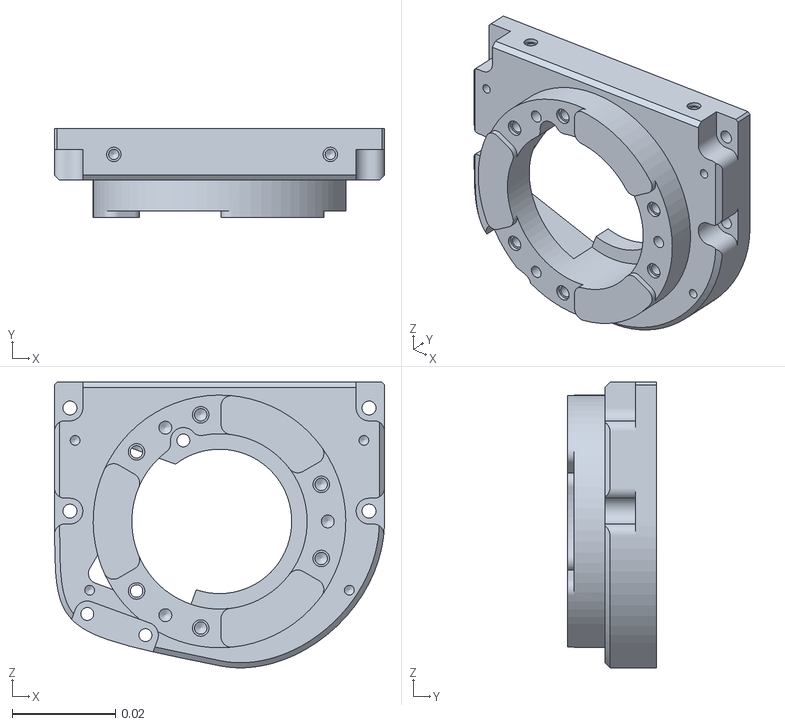
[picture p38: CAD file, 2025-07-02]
Demo/AHSimulation/AHSimulation/AH_Right/mjcf/assets/r_wrist_interface.stl
0.064 x 0.0172 x 0.0554

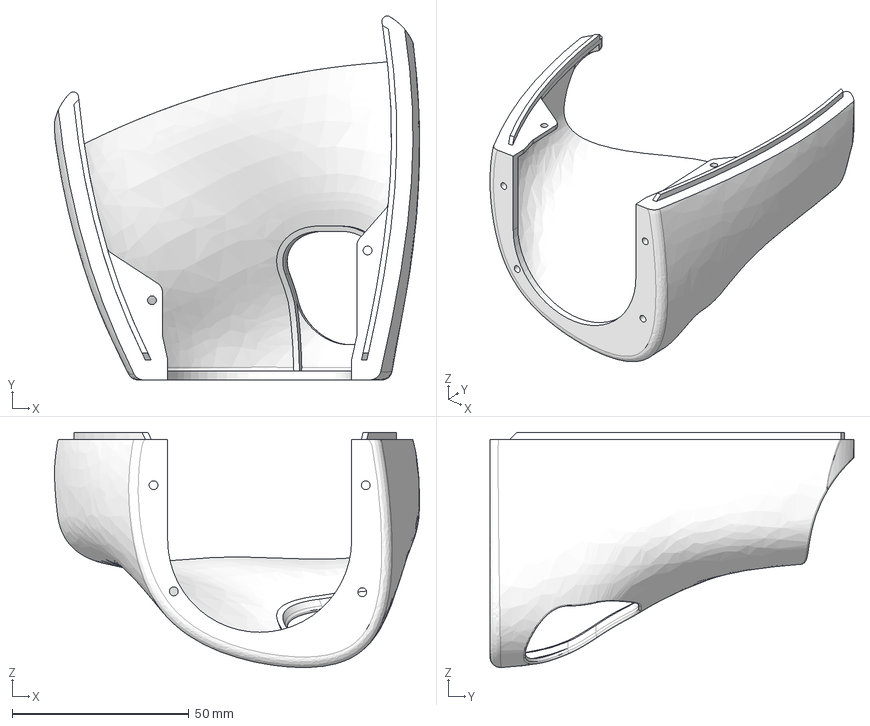
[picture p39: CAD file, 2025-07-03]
cad/step/Amazing Hand Parts - L-Palm_Shell.step
103.2 x 102.9 x 66.5 mm

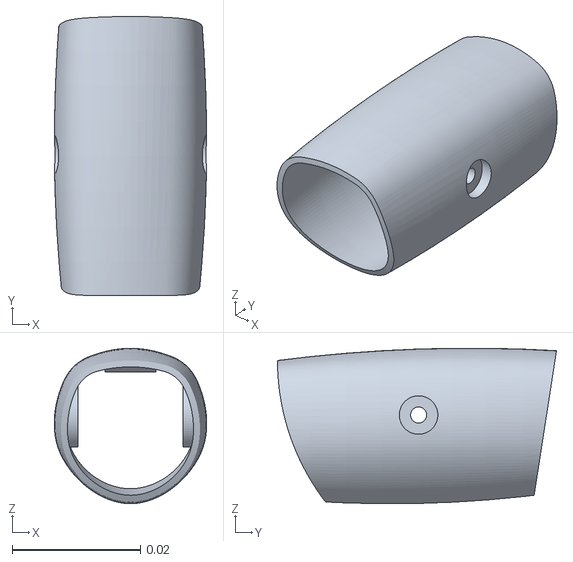
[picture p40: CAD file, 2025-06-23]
Demo/AHSimulation/AHSimulation/AH_Right/mjcf/assets/prox_shell.stl
0.0238 x 0.0435 x 0.0242

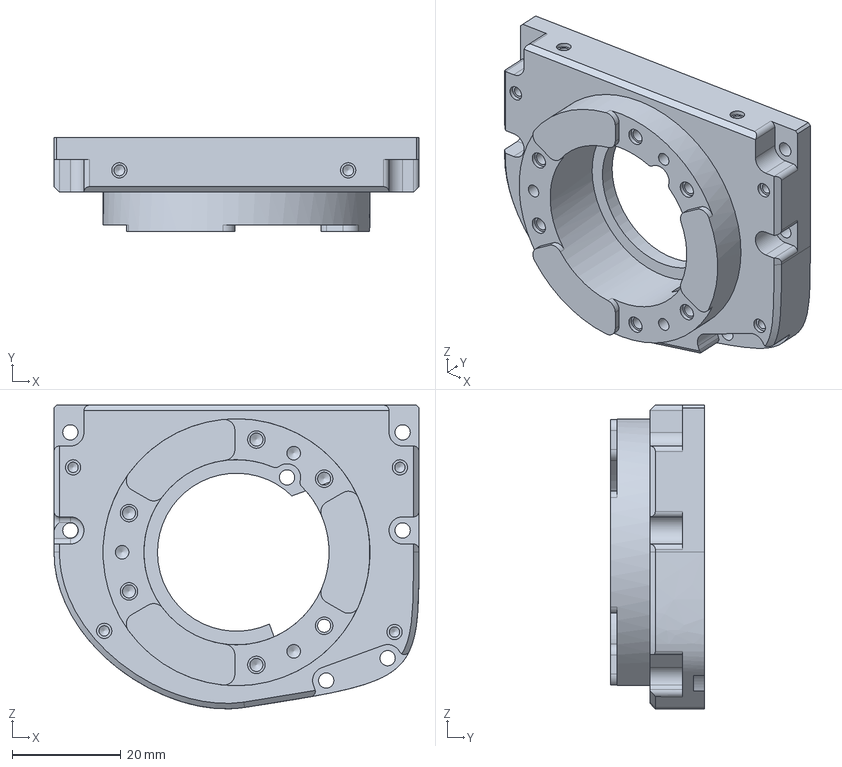
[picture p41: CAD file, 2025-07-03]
cad/step/Amazing Hand Parts - L-Wrist_Interface.step
67.0 x 17.2 x 55.7 mm

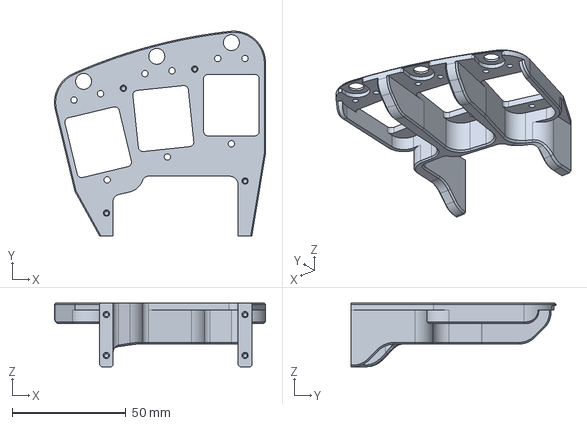
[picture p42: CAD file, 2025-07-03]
cad/step/Amazing Hand Parts - L-Hand_Plate.step
92.8 x 90.1 x 28.0 mm

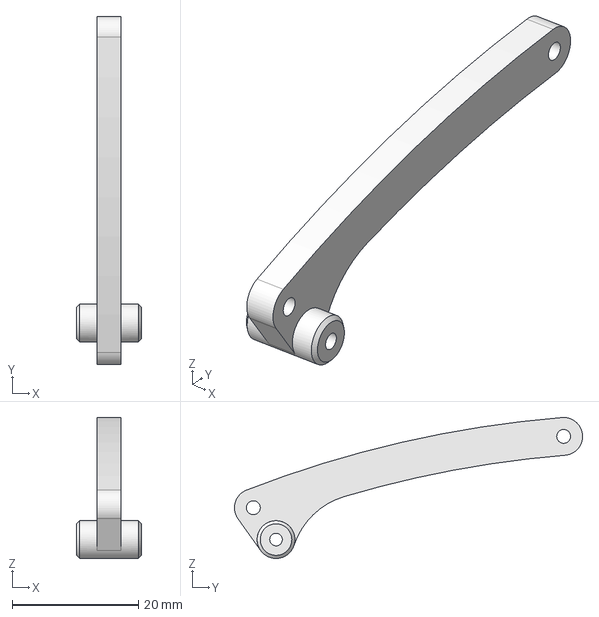
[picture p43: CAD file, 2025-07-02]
cad/step/Amazing Hand Parts - Link.step
10.3 x 55.2 x 22.4 mm

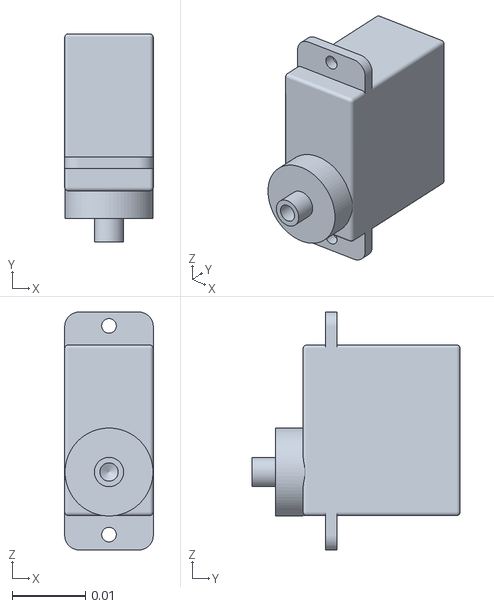
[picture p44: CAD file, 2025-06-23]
Demo/AHSimulation/AHSimulation/AH_Right/mjcf/assets/scs0009.stl
0.0121 x 0.0285 x 0.0325

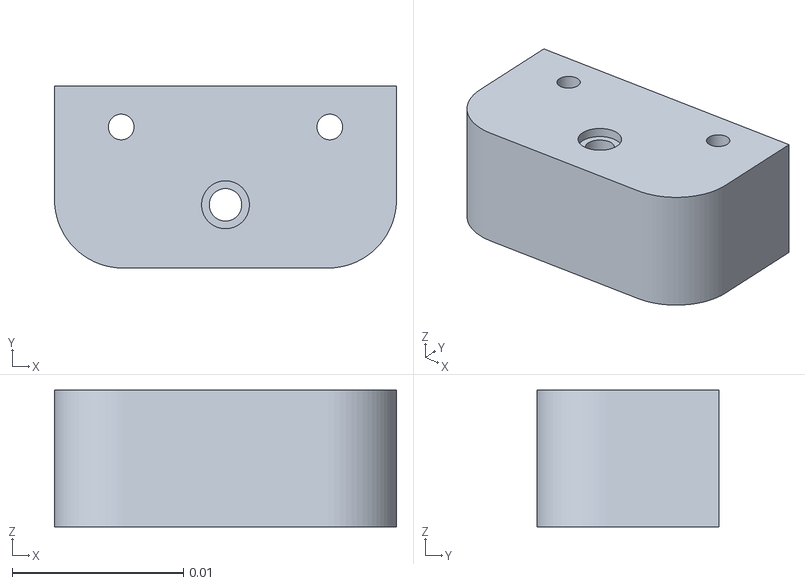
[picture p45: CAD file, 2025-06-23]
Demo/AHSimulation/AHSimulation/AH_Right/mjcf/assets/finger_frame_2.stl
0.02 x 0.0107 x 0.008

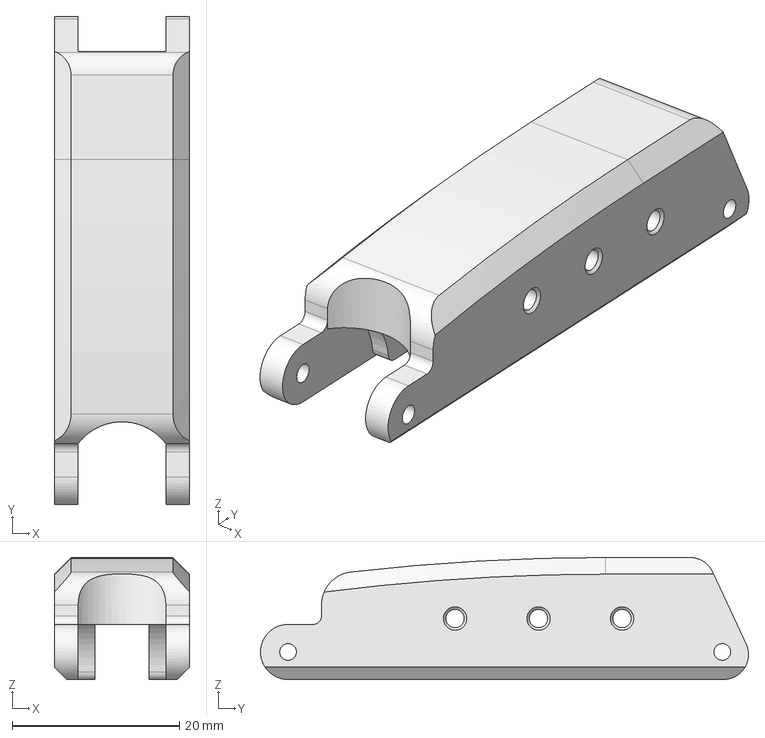
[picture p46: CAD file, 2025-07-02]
cad/step/Amazing Hand Parts - Proximal.step
16.2 x 58.4 x 14.6 mm

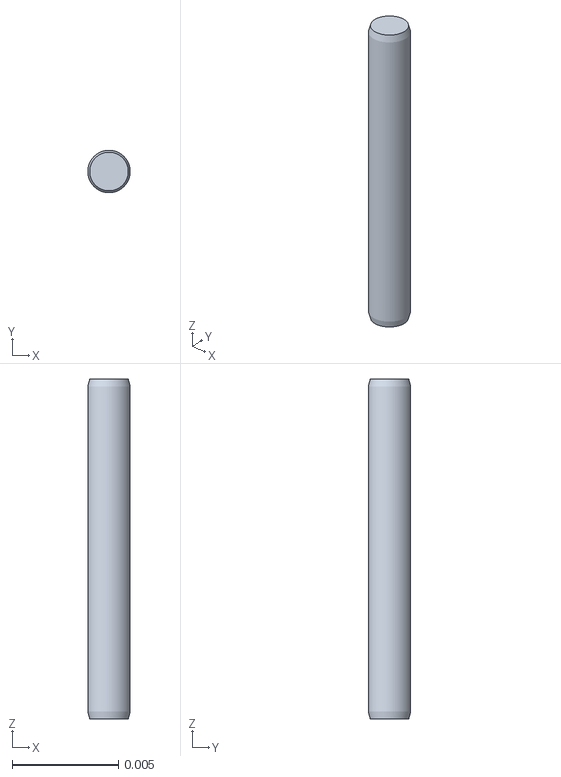
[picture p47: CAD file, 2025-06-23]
Demo/AHSimulation/AHSimulation/AH_Right/mjcf/assets/parallel_pin_2_x_16__da4b7ddbe9d803fe3fbc70f2e822b99b.stl
0.002 x 0.002 x 0.016

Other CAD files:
cad/step/Amazing Hand Parts - R-Top_Shell.step
cad/step/BallJoint_Rod - Spacer.step
cad/step/Amazing Hand Parts - Distal.step
Demo/AHSimulation/AHSimulation/AH_Right/mjcf/assets/dist.stl
Demo/AHSimulation/AHSimulation/AH_Right/mjcf/assets/dist_shell.stl
Demo/AHSimulation/AHSimulation/AH_Right/mjcf/assets/finger_frame_1.stl
Demo/AHSimulation/AHSimulation/AH_Right/mjcf/assets/gimbal.stl
Demo/AHSimulation/AHSimulation/AH_Right/mjcf/assets/link.stl
Demo/AHSimulation/AHSimulation/AH_Right/mjcf/assets/parallel_pin_2_x_10__fee063fca0c8b40e46bbc4ffff61d999.stl
Demo/AHSimulation/AHSimulation/AH_Right/mjcf/assets/part_1.stl
Demo/AHSimulation/AHSimulation/AH_Right/mjcf/assets/part_1__2.stl
Demo/AHSimulation/AHSimulation/AH_Right/mjcf/assets/ph_pan_head_screw_m2x0_40_x_10__2803432263e518bbd16bccbbef8784ed.stl
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

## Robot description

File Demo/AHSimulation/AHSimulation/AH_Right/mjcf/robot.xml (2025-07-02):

<?xml version="1.0" ?>
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
<mujoco model="mjcf">
  <compiler angle="radian" meshdir="assets" autolimits="true"/>
  <default>
    <default class="mjcf">
      <joint frictionloss="0.1" armature="0.005"/>
      <position kp="50" dampratio="1"/>
      <default class="visual">
        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
      </default>
      <default class="collision">
        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
      </default>
    </default>
  </default>
  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
  <default>
    <default class="perfect_actuator">
      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
      <joint damping="0.095" frictionloss="0.001" armature="0.001" range="-1.5707963267948966 1.5707963267948966"/>
      <position kp="10.0" kv="0.0" forcerange="-10.0 10.0"/>
      <default class="chosen_actuator"/>
    </default>
    <default class="xc330m288t">
      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
      <joint damping="0.095" frictionloss="0.058" armature="0.0018"/>
      <position kp="2.54" kv="0.0" forcerange="-0.8 0.8"/>
    </default>
    <default class="sts3215_345">
      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
      <joint damping="0.56" frictionloss="0.068" armature="0.027"/>
      <position kp="17.11" kv="0.0" forcerange="-3.23 3.23"/>
    </default>
    <default class="sts3215_147">
      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
      <joint damping="0.1" frictionloss="0.028" armature="0.011"/>
      <position kp="17.11" kv="0.0" forcerange="-1.35 1.35"/>
    </default>
  </default>
  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
  <default>
    <equality solref="0.002 1" solimp="0.99 0.999 0.0005 0.5 2"/>
  </default>
  <worldbody>
    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
    <body name="r_wrist_interface" pos="0 0 0" quat="1 0 0 0" childclass="mjcf">
      <inertial pos="0 0 0" mass="1e-09" fullinertia="1e-09 1e-09 1e-09 0 0 0"/>
      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
      <body name="part_1" pos="-0.00755 0.0291 0.0802" quat="0.5 0.5 -0.5 -0.5">
        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
        <joint axis="0 0 1" name="finger1_motor1" type="hinge" range="-1.570796326794893 1.5707963267949"/>
        <inertial pos="-0.005 2.13112e-17 -0.00705938" mass="0.000410988" fullinertia="4.63584e-09 4.63584e-09 1e-09 1.74248e-23 -6.56433e-24 -6.16387e-25"/>
        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
        <body name="rotule_lever" pos="-0.005 2.77556e-17 -0.0074" quat="5.17779e-18 1 -3.19189e-16 5.0307e-17">
          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
          <joint axis="0 0 1" name="passive_ball4 (1)" type="ball"/>
          <inertial pos="0.00144941 -0.0114013 0.000398122" mass="0.00037463" fullinertia="2.61636e-08 1.81369e-09 2.65334e-08 3.14636e-09 -1.0991e-10 8.6423e-10"/>
          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
          <body name="rotule_ball" pos="0.00289882 -0.0228027 0.000796243" quat="0.17095 0.68638 0.169947 0.686131">
            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
            <joint axis="0 0 1" name="passive_ball2 (1)" type="ball"/>
            <inertial pos="-0.00660134 0.0114927 0.0083" mass="0.00280216" fullinertia="7.23919e-07 1.86013e-07 7.7778e-07 2.48635e-07 9.28924e-22 -1.24904e-22"/>
            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
            <body name="std00333_plast_tcb_torx_2_5x8__configuration_copy_of_default" pos="-0.00505081 -0.00359574 0.0102" quat="1.09151e-15 -0.707107 -0.707107 -8.46594e-16">
              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
              <joint axis="0 0 1" name="passive2 (1)" type="hinge"/>
              <inertial pos="-0.00470584 -0.00888884 0.002" mass="0.00182517" fullinertia="9.41141e-08 3.76869e-08 1.1114e-07 -4.15062e-08 -8.13726e-22 9.9544e-22"/>
              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
            </body>
            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
            <body name="parallel_pin_2_x_10__fee063fca0c8b40e46bbc4ffff61d999" pos="-0.0163658 0.0456203 0.0064" quat="0.707107 1.09151e-15 -7.77156e-16 0.707107">
              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
              <joint axis="0 0 1" name="passive4 (1)" type="hinge"/>
              <inertial pos="0.0152038 -0.0125397 0.002" mass="0.00544752" fullinertia="3.28761e-07 5.94668e-07 7.81086e-07 3.29432e-07 8.56995e-21 1.3265e-20"/>
              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
              <body name="parallel_pin_2_x_16__da4b7ddbe9d803fe3fbc70f2e822b99b" pos="-2.33709e-05 -0.00599995 0.0068" quat="2.74651e-15 -1 -0.000118767 -8.17262e-15">
                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
                <joint axis="0 0 1" name="passive_5 (1)" type="hinge"/>
                <inertial pos="-0.0249801 -0.00389919 0.00508577" mass="0.0104554" fullinertia="5.04428e-07 2.60905e-06 2.4369e-06 2.43136e-08 1.26776e-10 2.98911e-10"/>
                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
              </body>
            </body>
          </body>
        </body>
      </body>
      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
      <body name="rotule_ball_2" pos="-0.00755 0.0169 0.0802" quat="0.5 -0.5 -0.5 0.5">
        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
        <joint axis="0 0 1" name="finger1_motor2" type="hinge" range="-1.5707963267949117 1.5707963267948815"/>
        <inertial pos="-0.005 1.23547e-17 -0.00705938" mass="0.000410988" fullinertia="4.63584e-09 4.63584e-09 1e-09 2.44005e-23 -3.52174e-24 -1.04761e-24"/>
        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
        <body name="rotule_lever_2" pos="-0.005 1.38778e-17 -0.0074" quat="1.16206e-16 -1 1.31839e-15 -2.32453e-16">
          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
          <joint axis="0 0 1" name="passive_ball3 (1)" type="ball"/>
          <inertial pos="0.0013506 0.0114135 0.000398122" mass="0.00037463" fullinertia="2.62162e-08 1.76101e-09 2.65334e-08 -2.93498e-09 -1.02333e-10 -8.65162e-10"/>
          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
        </body>
      </body>
      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
      <body name="part_1_2" pos="-0.00755 -3.35429e-05 0.0756068" quat="0.459229 0.537688 -0.459229 -0.537688">
        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
        <joint axis="0 0 1" name="finger2_motor1" type="hinge" range="-1.5707963267948903 1.5707963267949028"/>
        <inertial pos="-0.005 4.66732e-17 -0.00705938" mass="0.000410988" fullinertia="4.63584e-09 4.63584e-09 1e-09 1.70007e-23 -1.17063e-23 -7.63301e-25"/>
        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
        <body name="rotule_lever_3" pos="-0.005 4.16334e-17 -0.0074" quat="2.5507e-19 1 -3.21248e-16 2.07165e-16">
          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
          <joint axis="0 0 1" name="passive_ball4 (2)" type="ball"/>
          <inertial pos="0.00144941 -0.0114013 0.000398122" mass="0.00037463" fullinertia="2.61636e-08 1.81369e-09 2.65333e-08 3.14636e-09 -1.09889e-10 8.64232e-10"/>
          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
          <body name="rotule_ball_3" pos="0.00289882 -0.0228027 0.000796243" quat="0.17095 0.68638 0.169947 0.686131">
            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
            <joint axis="0 0 1" name="passive_ball2 (2)" type="ball"/>
            <inertial pos="-0.00660134 0.0114927 0.0083" mass="0.00280216" fullinertia="7.23919e-07 1.86013e-07 7.7778e-07 2.48635e-07 1.37519e-21 2.29956e-22"/>
            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
            <body name="std00333_plast_tcb_torx_2_5x8__configuration_copy_of_default_2" pos="-0.00505081 -0.00359574 0.0102" quat="1.15091e-15 -0.707107 -0.707107 -7.12689e-16">
              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
              <joint axis="0 0 1" name="passive2 (2)" type="hinge"/>
              <inertial pos="-0.00470584 -0.00888884 0.002" mass="0.00182517" fullinertia="9.41141e-08 3.76869e-08 1.1114e-07 -4.15062e-08 -9.01025e-22 8.39048e-22"/>
              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
            </body>
            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
            <body name="parallel_pin_2_x_10__fee063fca0c8b40e46bbc4ffff61d999_2" pos="-0.0163658 0.0456203 0.0064" quat="0.707107 1.15091e-15 -6.66134e-16 0.707107">
              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
              <joint axis="0 0 1" name="passive4 (2)" type="hinge"/>
              <inertial pos="0.0152038 -0.0125397 0.002" mass="0.00544752" fullinertia="3.28761e-07 5.94668e-07 7.81086e-07 3.29432e-07 8.90379e-21 1.39205e-20"/>
              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
              <body name="parallel_pin_2_x_16__da4b7ddbe9d803fe3fbc70f2e822b99b_2" pos="-2.33709e-05 -0.00599995 0.0068" quat="2.39218e-15 -1 -0.000118767 -8.44675e-15">
                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
                <joint axis="0 0 1" name="passive_5 (2)" type="hinge"/>
                <inertial pos="-0.0249801 -0.00389919 0.00508577" mass="0.0104554" fullinertia="5.04428e-07 2.60905e-06 2.4369e-06 2.43136e-08 1.26776e-10 2.98911e-10"/>
                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
              </body>
            </body>
          </body>
        </body>
      </body>
      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
      <body name="rotule_ball_4" pos="-0.00755 -0.0120833 0.0736983" quat="0.537688 -0.459229 -0.537688 0.459229">
        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
        <joint axis="0 0 1" name="finger2_motor2" type="hinge" range="-1.5707963267948988 1.5707963267948943"/>
        <inertial pos="-0.005 1.23132e-17 -0.00705938" mass="0.000410988" fullinertia="4.63584e-09 4.63584e-09 1e-09 2.47163e-23 -1.53952e-24 -1.01885e-24"/>
        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

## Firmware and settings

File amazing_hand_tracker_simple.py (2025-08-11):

#!/usr/bin/env python3
"""
AmazingHand Tracker - Simplified Version
A simplified version that uses basic inverse kinematics without complex Mujoco setup.
Now integrated with scservo_sdk for reliable motor control.

GPU Support:
- Use --gpu flag to enable GPU acceleration
- Install requirements_gpu.txt for GPU dependencies
- Requires NVIDIA GPU with CUDA support
- Falls back to CPU if GPU not available
"""

import argparse
import cv2
import numpy as np
import time
import json
import os
import math
from pathlib import Path
import mediapipe as mp
import threading

# MediaPipe setup
mp_drawing = mp.solutions.drawing_utils
mp_drawing_styles = mp.solutions.drawing_styles
mp_hands = mp.solutions.hands
HandLandmark = mp.solutions.hands.HandLandmark

# SCServo SDK imports
try:
    from scservo_sdk import PortHandler, PacketHandler, COMM_SUCCESS
except Exception as e:
    print(f"ERROR: scservo_sdk not found: {e}")
    print("Please ensure the scservo_sdk folder is in the current directory")
    raise

# SCS0009 constants from working code
ADDR_MODE = 33
ADDR_TORQUE_ENABLE = 40
ADDR_GOAL_POS = 42
ADDR_RUN_TIME = 44
ADDR_RUN_SPEED = 46

# Motor control constants
DEFAULT_TIME = 200
DEFAULT_SPEED = 800
CENTER_POS = 512  # Center position for 0-1023 range
OPEN_POS = 300
CLOSE_POS = 700

# Control parameters
LP_ALPHA = 0.25
SEND_PERIOD = 0.04

class SimpleAmazingHandController:
    """Simplified controller for the AmazingHand robot."""
    
    def __init__(self, config_file="config/r_hand.json", serial_port="COM3", 
                 baudrate=1000000, simulation_mode=False, hand_side="right", use_gpu=False):
        """
        Initialize the simplified AmazingHand controller.
        
        Args:
            config_file: Path to motor configuration file
            serial_port: Serial port for motor communication
            baudrate: Baud rate for serial communication
            simulation_mode: If True, only run simulation without real motors
            hand_side: "right" or "left" hand
            use_gpu: If True, attempt to use GPU acceleration for MediaPipe
        """
        self.simulation_mode = simulation_mode
        self.hand_side = hand_side
        self.serial_port = serial_port
        self.baudrate = baudrate
        self.use_gpu = use_gpu
        
        # Load motor configuration
        self.load_motor_config(config_file)
        
        # Initialize components
        if not simulation_mode:
            self.init_motor_controller()
        
        self.init_hand_tracking()
        
        # Control parameters
        self.fps = 30
        self.running = False
        self.use_advanced_ik = False  # Default to simple IK
        self.use_curl_ik = True       # Default to curl-based IK (better thumb control)
        self.debug_enabled = False    # Default to no debug output
        
        # IK parameters
        self.finger_lengths = [0.04, 0.04, 0.04, 0.04]  # Length of each finger segment
        self.max_angles = [np.pi/2, np.pi/2]  # Max angles for each joint
        
    def load_motor_config(self, config_file):
        """Load motor configuration from JSON file."""
        if os.path.exists(config_file):
            with open(config_file, 'r') as f:
                self.motor_config = json.load(f)
        else:
            # Default configuration for right hand
            self.motor_config = {
                "fingers": [
                    {
                        "name": "finger1",
                        "motor1": {"id": 1, "offset": 0.12217304763960307, "invert": False},
                        "motor2": {"id": 2, "offset": 0.08726646259971647, "invert": False}
                    },
                    {
                        "name": "finger2", 
                        "motor1": {"id": 3, "offset": 0.0, "invert": False},
                        "motor2": {"id": 4, "offset": 0.12217304763960307, "invert": False}
                    },
                    {
                        "name": "finger3",
                        "motor1": {"id": 5, "offset": 0.08726646259971647, "invert": False},
                        "motor2": {"id": 6, "offset": 0.12217304763960307, "invert": False}
                    },
                    {
                        "name": "finger4",
                        "motor1": {"id": 7, "offset": 0.0, "invert": False},
                        "motor2": {"id": 8, "offset": 0.12217304763960307, "invert": False}
                    }
                ]
            }
            print(f"Using default motor configuration. Save to {config_file} to customize.")
    
    def init_motor_controller(self):
        """Initialize the motor controller for SCS0009 servos using scservo_sdk."""
        try:
            print(f"Attempting to connect to motors on {self.serial_port}...")
            
            # Initialize PortHandler
            self.port_handler = PortHandler(self.serial_port)
            if not self.port_handler.openPort():
                print(f"Failed to open port {self.serial_port}")
                return
            
            # Set port baudrate
            if not self.port_handler.setBaudRate(self.baudrate):
                print(f"Failed to set baudrate {self.baudrate}")
                return
            
            # Initialize PacketHandler
            self.packet_handler = PacketHandler(self.port_handler)
            
            # Get motor IDs from config
            motor_ids = []
            for finger in self.motor_config["fingers"]:
                motor_ids.extend([finger["motor1"]["id"], finger["motor2"]["id"]])
            
            print(f"Motor IDs: {motor_ids}")
            
            # Test communication with each motor using ping
            print("Testing motor communication...")
            found_motors = []
            for motor_id in motor_ids:
                try:
                    model, res, err = self.packet_handler.ping(self.port_handler, motor_id)
                    if res == COMM_SUCCESS and err == 0:
                        print(f"✓ Motor {motor_id} responds (model={model})")
                        found_motors.append(motor_id)
                    else:
                        print(f"⚠ Motor {motor_id} no response")
                except Exception as e:
                    print(f"✗ Motor {motor_id} error: {e}")
            
            if not found_motors:
                print("No motors found! Running in simulation mode only")
                self.simulation_mode = True
                return
            
            # Initialize found motors
            print("Initializing found motors...")
            self.bus_init(found_motors)
            
            print("✓ Motor initialization completed")
            
        except Exception as e:
            print(f"✗ Failed to connect to motors: {e}")
            print("Running in simulation mode only")
            self.simulation_mode = True
    
    def bus_init(self, motor_ids):
        """Initialize motors: set position mode, enable torque, and center."""
        print("[DIAG] Forcing Position Mode, enabling torque, and centering...")
        
        # Set position mode for all motors
        for motor_id in motor_ids:
            self.set_position_mode(motor_id)
        time.sleep(0.05)
        
        # Enable torque for all motors
        for motor_id in motor_ids:
            self.set_torque(motor_id, True)
        time.sleep(0.05)
        
        # Move motors to center position
        for motor_id in motor_ids:
            self.move_servo(motor_id, CENTER_POS, run_time=250, run_speed=600)
        time.sleep(0.3)
    
    def set_position_mode(self, motor_id):
        """Set motor to position mode."""
        return self.packet_handler.write1ByteTxRx(self.port_handler, motor_id, ADDR_MODE, 0)
    
    def set_torque(self, motor_id, on=True):
        """Enable or disable torque for a motor."""
        return self.packet_handler.write1ByteTxRx(self.port_handler, motor_id, ADDR_TORQUE_ENABLE, 1 if on else 0)
    
    def move_servo(self, motor_id, pos, run_time=DEFAULT_TIME, run_speed=DEFAULT_SPEED):
        """Move servo to position with specified time and speed."""
        pos = int(max(0, min(1023, pos))) & 0xFFFF
        run_time = int(max(0, min(1023, run_time))) & 0xFFFF
        run_speed = int(max(0, min(1023, run_speed))) & 0xFFFF
        
        print(f"DEBUG: move_servo - motor {motor_id}, pos {pos}, time {run_time}, speed {run_speed}")
        
        try:
            result1, error1 = self.packet_handler.write2ByteTxRx(self.port_handler, motor_id, ADDR_GOAL_POS, pos)
            result2, error2 = self.packet_handler.write2ByteTxRx(self.port_handler, motor_id, ADDR_RUN_TIME, run_time)
            result3, error3 = self.packet_handler.write2ByteTxRx(self.port_handler, motor_id, ADDR_RUN_SPEED, run_speed)
            
            print(f"DEBUG: move_servo results - pos: ({result1}, {error1}), time: ({result2}, {error2}), speed: ({result3}, {error3})")
            
            # Check if any command failed - COMM_SUCCESS is 0, so we check for 0
            if result1 == 0 and result2 == 0 and result3 == 0:
                print(f"DEBUG: move_servo SUCCESS for motor {motor_id}")
                return True
            else:
                print(f"DEBUG: move_servo failed for motor {motor_id} - pos: ({result1}, {error1}), time: ({result2}, {error2}), speed: ({result3}, {error3})")
                return False
                
        except Exception as e:
            print(f"DEBUG: move_servo exception for motor {motor_id}: {e}")
            return False
    
    def init_hand_tracking(self):
        """Initialize MediaPipe hand tracking with optional GPU acceleration."""
        # Check for GPU availability
        gpu_available = self.check_gpu_availability()
        
        if self.use_gpu and gpu_available:
            print("GPU acceleration enabled for MediaPipe")
            # Use higher model complexity for better accuracy with GPU
            self.hands = mp_hands.Hands(
                model_complexity=1,  # Higher complexity for GPU
                min_detection_confidence=0.5,
                min_tracking_confidence=0.5,
                max_num_hands=2  # Support multiple hands with GPU
            )
        else:
            if self.use_gpu and not gpu_available:
                print("GPU requested but not available, falling back to CPU")
            else:
                print("CPU mode for MediaPipe")
            
            self.hands = mp_hands.Hands(
                model_complexity=0,  # Lower complexity for CPU
                min_detection_confidence=0.5,
                min_tracking_confidence=0.5,
                max_num_hands=1  # Single hand for CPU
            )
        
        print("Hand tracking initialized")
    
    def check_gpu_availability(self):
        """Check if GPU acceleration is available for MediaPipe."""
        try:
            # Check if CUDA is available for OpenCV
            if hasattr(cv2, 'cuda') and cv2.cuda.getCudaEnabledDeviceCount() > 0:
                print(f"CUDA GPU detected: {cv2.cuda.getCudaEnabledDeviceCount()} device(s)")
                return True
            
            # Check if MediaPipe GPU is available
            try:
                import mediapipe_gpu
                print("MediaPipe GPU package detected")
                return True
            except ImportError:
                pass
            
            # Check for other GPU indicators
            try:
                import torch
                if torch.cuda.is_available():
                    print(f"PyTorch CUDA detected: {torch.cuda.device_count()} device(s)")
                    return True
            except ImportError:
                pass
            
            print("No GPU acceleration detected, using CPU")
            return False
            
        except Exception as e:
            print(f"GPU detection error: {e}")
            return False
    
    def process_hand_landmarks(self, image):
        """Process hand landmarks from MediaPipe with GPU optimization."""
        # Convert to RGB for MediaPipe
        image_rgb = cv2.cvtColor(image, cv2.COLOR_BGR2RGB)
        
        # GPU optimization: resize image for better performance if GPU is available
        if self.use_gpu and hasattr(self, 'gpu_available') and self.gpu_available:
            # For GPU, we can use higher resolution for better accuracy
            height, width = image_rgb.shape[:2]
            if width > 640:  # Only resize if image is too large
                scale_factor = 640 / width
                new_width = int(width * scale_factor)
                new_height = int(height * scale_factor)
                image_rgb = cv2.resize(image_rgb, (new_width, new_height))
                if self.debug_enabled:
                    print(f"GPU mode: resized image to {new_width}x{new_height}")
        
        results = self.hands.process(image_rgb)
        
        if results.multi_hand_landmarks and results.multi_hand_world_landmarks:
            for idx, handedness in enumerate(results.multi_handedness):
                # Check if it's the correct hand
                if (handedness.classification[0].label == 'Right' and 
                    handedness.classification[0].score > 0.8 and 
                    self.hand_side == "right"):
                    
                    hand_landmarks = results.multi_hand_world_landmarks[idx]
                    hand_landmarks_norm = results.multi_hand_landmarks[idx]
                    
                    # Extract finger tip positions and angles
                    finger_data = self.extract_finger_data(hand_landmarks)
                    
                    return finger_data, hand_landmarks_norm
        
        return None, None
    
    def extract_finger_data(self, hand_landmarks):
        """Extract finger data including positions and angles."""
        
        finger_data = {}
        finger_mappings = {
            'finger1': [
                HandLandmark.INDEX_FINGER_MCP,
                HandLandmark.INDEX_FINGER_PIP,
                HandLandmark.INDEX_FINGER_DIP,
                HandLandmark.INDEX_FINGER_TIP
            ],
            'finger2': [
                HandLandmark.MIDDLE_FINGER_MCP,
                HandLandmark.MIDDLE_FINGER_PIP,
                HandLandmark.MIDDLE_FINGER_DIP,
                HandLandmark.MIDDLE_FINGER_TIP
            ],
            'finger3': [
                HandLandmark.RING_FINGER_MCP,
                HandLandmark.RING_FINGER_PIP,
                HandLandmark.RING_FINGER_DIP,
                HandLandmark.RING_FINGER_TIP
            ],
            'finger4': [
                HandLandmark.THUMB_MCP,
                HandLandmark.THUMB_IP,
                HandLandmark.THUMB_TIP
            ]
        }
        
        for finger_name, landmarks in finger_mappings.items():
            if len(landmarks) == 4:  # 3-joint finger
                positions = []
                for landmark in landmarks:
                    pos = hand_landmarks.landmark[landmark]
                    positions.append([pos.x, pos.y, pos.z])
                
                # Calculate angles between segments
                angles = self.calculate_finger_angles(positions)
                finger_data[finger_name] = {
                    'positions': positions,
                    'angles': angles
                }
            elif len(landmarks) == 3:  # 2-joint finger (thumb)
                positions = []
                for landmark in landmarks:
                    pos = hand_landmarks.landmark[landmark]
                    positions.append([pos.x, pos.y, pos.z])
                
                # Calculate angles for thumb
                angles = self.calculate_finger_angles(positions)
                
                # For thumb, calculate an additional angle based on thumb orientation
                # This helps coordinate the two thumb motors better
                if len(angles) >= 1:
                    # Calculate thumb orientation relative to palm
                    thumb_mcp = np.array(positions[0])
                    thumb_tip = np.array(positions[2])
                    
                    # Get wrist position for palm reference
                    wrist_pos = np.array([
                        hand_landmarks.landmark[HandLandmark.WRIST].x,
                        hand_landmarks.landmark[HandLandmark.WRIST].y,
                        hand_landmarks.landmark[HandLandmark.WRIST].z
                    ])
                    
                    # Calculate thumb spread angle (sideways movement)
                    palm_vector = thumb_mcp - wrist_pos
                    thumb_vector = thumb_tip - thumb_mcp
                    
                    # Project onto palm plane and calculate spread angle
                    palm_normal = np.array([0, 0, 1])  # Assuming palm faces camera
                    palm_vector_proj = palm_vector - np.dot(palm_vector, palm_normal) * palm_normal
                    thumb_vector_proj = thumb_vector - np.dot(thumb_vector, palm_normal) * palm_normal
                    
                    if np.linalg.norm(palm_vector_proj) > 0 and np.linalg.norm(thumb_vector_proj) > 0:
                        cos_spread = np.dot(palm_vector_proj, thumb_vector_proj) / (np.linalg.norm(palm_vector_proj) * np.linalg.norm(thumb_vector_proj))
                        cos_spread = np.clip(cos_spread, -1.0, 1.0)
                        spread_angle = np.arccos(cos_spread)
                        angles.append(spread_angle)
                    else:
                        angles.append(0.0)
                
                finger_data[finger_name] = {
                    'positions': positions,
                    'angles': angles
                }
        
        return finger_data
    
    def calculate_finger_angles(self, positions):
        """Calculate angles between finger segments."""
        if len(positions) < 3:
            return []
        
        angles = []
        for i in range(len(positions) - 2):
            # Calculate vectors between three consecutive points
            v1 = np.array(positions[i+1]) - np.array(positions[i])
            v2 = np.array(positions[i+2]) - np.array(positions[i+1])
            
            # Calculate angle between vectors
            cos_angle = np.dot(v1, v2) / (np.linalg.norm(v1) * np.linalg.norm(v2))
            cos_angle = np.clip(cos_angle, -1.0, 1.0)  # Clamp to valid range
            angle = np.arccos(cos_angle)
            angles.append(angle)
        
        return angles
    
    def compute_curls_from_landmarks(self, hand_landmarks):
        """Compute finger curls based on distance between fingertip and MCP joint (like reference file)."""
        # Debug: Check input
        print(f"DEBUG: compute_curls_from_landmarks called with hand_landmarks: {hand_landmarks}")
        if hand_landmarks is None:
            print("DEBUG: hand_landmarks is None, returning empty curls")
            return {}
        
        # Define finger landmark pairs: (tip, mcp)
        finger_pairs = {
            'finger1': (HandLandmark.INDEX_FINGER_TIP, HandLandmark.INDEX_FINGER_MCP),
            'finger2': (HandLandmark.MIDDLE_FINGER_TIP, HandLandmark.MIDDLE_FINGER_MCP),
            'finger3': (HandLandmark.RING_FINGER_TIP, HandLandmark.RING_FINGER_MCP),
            'finger4': (HandLandmark.THUMB_TIP, HandLandmark.THUMB_MCP)
        }
        
        curls = {}
        for finger_name, (tip, mcp) in finger_pairs.items():
            try:
                # Get positions
                tip_pos = hand_landmarks.landmark[tip]
                mcp_pos = hand_landmarks.landmark[mcp]
                
                print(f"DEBUG: {finger_name} - tip_pos: ({tip_pos.x:.3f}, {tip_pos.y:.3f}), mcp_pos: ({mcp_pos.x:.3f}, {mcp_pos.y:.3f})")
                
                # Calculate 2D distance (ignore Z for curl calculation)
                d = math.hypot(tip_pos.x - mcp_pos.x, tip_pos.y - mcp_pos.y)
                
                # Map distance to curl value (0.0 = fully open, 1.0 = fully closed)
                # These values are tuned based on the reference file approach
                if finger_name == 'finger4':  # Thumb - improved curl detection for better alignment
                    # Improved curl detection for thumb - more sensitive and better aligned with MediaPipe
                    # This should make the thumb movement more obvious and correctly aligned
                    c = max(0.0, min(1.0, (0.30 - d) / 0.20))
                else:  # Other fingers - much more sensitive curl detection for maximum bending
                    # Make other fingers much more sensitive to allow them to bend fully
                    c = max(0.0, min(1.0, (0.20 - d) / 0.12))  # Even more sensitive range
                
                print(f"DEBUG: {finger_name} - distance: {d:.3f}, curl: {c:.3f}")
                
                curls[finger_name] = c
                
            except (IndexError, AttributeError) as e:
                print(f"DEBUG: Error processing {finger_name}: {e}")
                continue
        
        print(f"DEBUG: Final curls dictionary: {curls}")
        return curls
    
    def curl_based_inverse_kinematics(self, hand_landmarks):
        """Simple curl-based IK that maps finger curls directly to servo positions."""
        print(f"DEBUG: curl_based_inverse_kinematics called with hand_landmarks: {hand_landmarks}")
        
        curls = self.compute_curls_from_landmarks(hand_landmarks)
        print(f"DEBUG: Received curls: {curls}")
        
        if not curls:
            print("DEBUG: No curls received, returning empty joint_positions")
            return {}
        
        # Configuration for curl-based control
        CENTER_POS = 512
        # Increase gain for more aggressive bending - allow fingers to bend more fully
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

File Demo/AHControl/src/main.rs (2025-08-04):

use clap::Parser;
// use dora_node_api::{dora_core::config::NodeId, DoraNode, Event};

// use dora_node_api::IntoArrow;
use dora_node_api::{
    self, arrow::array::Array, dora_core::config::NodeId, DoraNode, Event, Parameter,
};
use eyre::{eyre, Result};
use rustypot::servo;
use std::{error::Error, time::Duration};

use facet::Facet;
use facet_pretty::FacetPretty;
// use std::{collections::HashMap, path::PathBuf, sync::Arc};
// use std::error::Error;
// use arrow_convert::{
//     deserialize::TryIntoCollection, serialize::TryIntoArrow, ArrowDeserialize, ArrowField,
//     ArrowSerialize,
// };
use std::{fs, thread};

// use std::io::Read;
#[derive(Debug, Facet)]
struct Fingers {
    #[allow(dead_code)] // Disable dead code warning for the entire struct
    motors: Vec<Motors>,
}

#[derive(Debug, Facet)]
struct Motors {
    #[allow(dead_code)] // Disable dead code warning for the entire struct
    finger_name: String,
    #[allow(dead_code)] // Disable dead code warning for the entire struct
    motor1: Motor,
    #[allow(dead_code)] // Disable dead code warning for the entire struct
    motor2: Motor,
}

#[derive(Debug, Facet)]
struct Motor {
    #[allow(dead_code)]
    id: u8,
    #[allow(dead_code)]
    offset: f64,
    #[allow(dead_code)]
    invert: bool,
    #[allow(dead_code)]
    model: String,
}

#[derive(Parser, Debug)]
#[command(author, version, about, long_about = None)]
struct Args {
    /// Serialport
    #[arg(short, long, default_value = "/dev/ttyACM0")]
    serialport: String,
    /// baudrate
    #[arg(short, long, default_value_t = 1_000_000)]
    baudrate: u32,
    /// TOML config file
    #[arg(short, long, default_value = "config/r_hand.toml")]
    config: String,
}

fn main() -> Result<(), Box<dyn Error>> {
    let args = Args::parse();
    let serialport: String = args.serialport;
    let baudrate: u32 = args.baudrate;
    let configfile: String = args.config;
    println!("Opening {:?}", configfile);
    let toml_str = fs::read_to_string(configfile).expect("Failed to read config file");

    let motors_conf: Fingers =
        facet_toml::from_str(&toml_str).expect("Failed to deserialize config file");

    println!("{}", motors_conf.pretty());
    let serial_port = serialport::new(serialport, baudrate)
        .timeout(Duration::from_millis(10))
        .open()?;

    let mut controller = servo::feetech::scs0009::Scs0009Controller::new()
        .with_protocol_v1()
        .with_serial_port(serial_port);

    if motors_conf.motors[0].motor1.model != *"SCS0009" {
        return Err(eyre!("Only SCS0009 motors are supported for now...").into());
    };

    // let output = DataId::from("pull_position".to_owned());
    let mut finger_names: Vec<String> = vec![];
    let mut motor_ids: Vec<u8> = vec![];
    let mut motor_offsets: Vec<f64> = vec![];
    let motors = &motors_conf.motors;
    for motors in motors {
        finger_names.push(motors.finger_name.clone());
        motor_ids.push(motors.motor1.id);
        motor_ids.push(motors.motor2.id);
        motor_offsets.push(motors.motor1.offset);
        motor_offsets.push(motors.motor2.offset);
    }
    let motors_on: Vec<u8> = vec![1; motor_ids.len()];
    let motors_off: Vec<u8> = vec![0; motor_ids.len()];

    //torque enable
    controller.sync_write_torque_enable(&motor_ids, &motors_on)?;
    thread::sleep(Duration::from_millis(1000));
    controller.sync_write_goal_position(&motor_ids, &motor_offsets)?;
    thread::sleep(Duration::from_millis(1000));
    let (mut _node, mut events) =
        // DoraNode::init_from_node_id(NodeId::from("hand_controller".to_string()))?;
        DoraNode::init_from_env()?;

    while let Some(event) = events.recv() {
        match event {
            Event::Input { id, metadata, data } => match id.as_str() {
                "mj_joints_pos" => {
                    let buffer: &dora_node_api::arrow::array::Float64Array =
                        data.as_any().downcast_ref().unwrap();
                    let buffer: &[f64] = buffer.values();
                    // println!("data: {:?}", buffer);

                    let mut motors_ids: Vec<u8> = Vec::new();
                    let mut motors_goalpos: Vec<f64> = Vec::new();

                    for (_idx, finger) in motors.iter().enumerate() {
                        // println!("conf: {:?} {:?}", idx, finger.finger_name);

                        if let Some(Parameter::ListInt(finger1_idx)) =
                            metadata.parameters.get(&finger.finger_name)
                        {
                            println!(
                                "metadata: {:?} data: {:?} {:?}",
                                finger1_idx,
                                buffer[finger1_idx[0] as usize],
                                buffer[finger1_idx[1] as usize]
                            );
                            // controller.sync_write_goal_position(
                            //     &[finger.motor1.id, finger.motor2.id],
                            //     &[
                            //         buffer[finger1_idx[0] as usize] + finger.motor1.offset,
                            //         buffer[finger1_idx[1] as usize] + finger.motor2.offset,
                            //     ],
                            // )?;

                            motors_ids.push(finger.motor1.id);
                            motors_ids.push(finger.motor2.id);

                            let mut m1goal = buffer[finger1_idx[0] as usize] + finger.motor1.offset;
                            if finger.motor1.invert {
                                m1goal = -m1goal;
                            }
                            motors_goalpos.push(m1goal);
                            let mut m2goal = buffer[finger1_idx[1] as usize] + finger.motor2.offset;
                            if finger.motor2.invert {
                                m2goal = -m2goal;
                            }
                            motors_goalpos.push(m2goal);
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

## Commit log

2025-06-24 add simple tools for motors setup
2025-07-02 add example for finger angle control
    [r_hand_plate.stl, r_wrist_interface.stl, robot.xml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]
2025-07-03 move step stl
    [Amazing Hand Parts - Distal.step, Amazing Hand Parts - Distal.stl, Amazing Hand Parts - Distal_Shell.step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]
2025-07-10 Update Assembly guide with IDs picture
2025-07-16 Update README.md
    Community update
    Amazing base & Chinese BOM from Jianliang Shen
2025-07-24 fix for issue #8 updated hardcoded servo ID=1 to ID_1 and ID_2 variables
2025-08-04 Update main.rs
    fix incorrect syntax for tuple variants.
    [main.rs]
2025-08-05 add connector support for so-100 arm
    3d print file include
    [Hand base connet_connector_so100.STL]
2025-08-10 Add Python-based hand tracking system with MediaPipe and inverse kinematics - Main tracking script (amazing_hand_tracker_simple.py) - Custom Feetech SCS0009 servo SDK (scservo_sdk/) - Robot hand conf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
2025-08-11 Add comprehensive GPU acceleration support with Python 3.12 compatibility
    - Add GPU acceleration support for MediaPipe hand tracking
    - Implement GPU detection and fallback mechanisms
    - Add --gpu and --gpu-test command line flags
    - Update README with GPU installation instructions and Python version compatibility
    - Create requirements_gpu.txt for GPU dependencies
    - Add GPU_ACCELERATION_STATUS.md explaining current limitations
    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

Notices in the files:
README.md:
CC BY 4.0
